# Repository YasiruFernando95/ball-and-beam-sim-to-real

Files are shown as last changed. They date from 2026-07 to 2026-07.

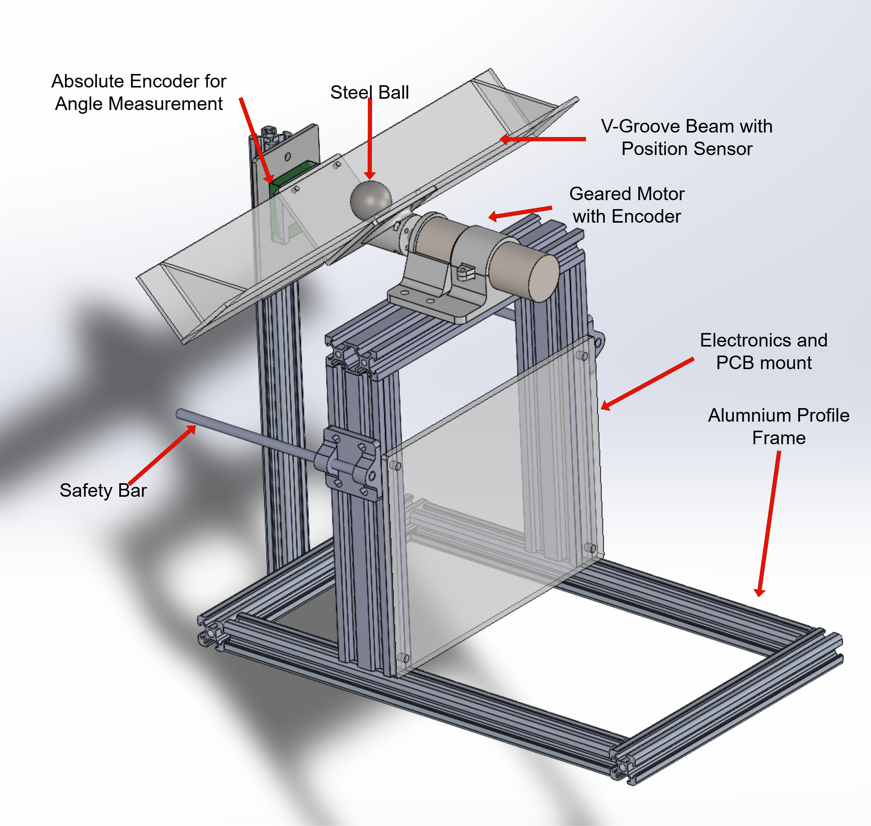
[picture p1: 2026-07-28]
hardware/prototype/diagrams/labelled_diagram.png

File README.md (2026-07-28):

# Ball-and-Beam Control System

A mechatronic ball-and-beam platform developed for classical control, reinforcement-learning control, and simulation-to-real experiments.

The system uses an STM32F401CCU6 microcontroller to regulate the beam angle through a geared DC motor. Ball position, ball velocity, beam angle, beam angular velocity, motor speed, and the commanded beam-angle setpoint are transmitted to a computer through USB CDC for monitoring, training, and evaluation.

Ball-and-beam system

## Project Status

Current status: **Functional experimental platform**

Implemented features:

- [x] Mechanical ball-and-beam platform
- [x] DC motor actuation
- [x] Motor encoder feedback
- [x] MT6816 absolute beam-angle sensing
- [x] Graphite-strip ball-position sensing
- [x] STM32 firmware
- [x] USB CDC telemetry
- [x] Inner PID beam-angle control
- [x] Beam-angle virtual walls and braking
- [x] PC-command timeout protection
- [x] PyBullet/Gymnasium RL simulation environment
- [x] Hardware interface for RL beam-angle commands

## Project Objectives

The project aims to:

- Develop a functional ball-and-beam experimental platform.
- Implement reliable real-time sensing and motor control.
- Train reinforcement-learning agents in a physics-based simulation.
- Transfer trained policies to the physical system.
- Compare classical and reinforcement-learning-based controllers.
- Evaluate tracking accuracy, settling behavior, control effort, robustness, and safety.

## System Overview

The controller changes the angle of a V-groove beam to regulate the position of a steel ball.

| Variable | Description | Unit |
|---|---|---|
| `x` | Ball position measured from the beam center | m |
| `xdot` | Filtered ball velocity | m/s |
| `theta` | Beam angle | degrees |
| `thetadot` | Filtered beam angular velocity | degrees/s |
| `omega` | Filtered geared-motor output speed | degrees/s |
| `theta_sp` | Beam-angle setpoint received from the PC | degrees |
| `u` | Inner PID motor command | normalized `-1` to `+1` |

The firmware executes its main sensing, telemetry, and beam-angle control block every **10 ms**, corresponding to **100 Hz**.

## Hardware

### Main Components

| Component | Model or specification | Purpose |
|---|---|---|
| Microcontroller | STM32F401CCU6 Black Pill | Real-time sensing and control |
| Motor | Cytron IG32E, 430 RPM, 14:1 | Beam actuation |
| Motor driver | Cytron MD10C R3 | Bidirectional motor drive |
| Motor encoder | 98 counts per motor revolution | Motor-speed feedback |
| Beam-angle sensor | MT6816 | Absolute beam-angle measurement |
| Ball-position sensor | Graphite-strip potentiometer | Ball-position measurement |
| Display | 0.96-inch SSD1306 OLED | Local measurements and status |
| Power supply | 12 V, 3 A | System power |
| Ball | 25 mm steel ball | Controlled object |
| Beam | 0.30 m acrylic V-groove | Ball rolling surface |

### Mechanical Specifications

| Parameter | Value |
|---|---:|
| Beam length | 0.30 m |
| Ball diameter | 25 mm |
| Firmware beam-angle limit | -25° to +25° |
| Beam construction | Acrylic V-groove |
| Motor gear ratio | 14:1 |
| Frame material | Aluminium extrusion |

### Firmware Peripheral Assignment

| Function | STM32 peripheral or signal | Purpose |
|---|---|---|
| Motor PWM | TIM3 Channel 1 | Motor command magnitude |
| Motor direction | GPIO PB3 | Motor direction |
| Motor encoder | TIM2 encoder mode | Motor-speed measurement |
| Beam-angle sensor | SPI1 with DMA | MT6816 communication |
| Ball-position sensor | ADC1 Channel 2 with DMA | Position-sensor voltage |
| OLED display | I2C1 with DMA | Local display |
| Control/update timer | TIM10 | Encoder and ADC updates |
| PC communication | USB CDC | Commands and telemetry |

A complete wiring diagram should be placed in:

```text
hardware/schematics/
```

## Firmware Architecture

The firmware uses the following custom modules:

```text
dist_adc
ssd1306
mt6816
encoder_speed
motor_driver
virtual_wall
pid
usb_telemetry
```

The main runtime sequence is:

1. Update the ADC-based ball-position measurement.
2. Read the MT6816 beam angle.
3. Estimate ball and beam velocities using filtered numerical derivatives.
4. Read the latest beam-angle setpoint received through USB CDC.
5. Transmit telemetry to the PC.
6. Apply the ±25° command clamp.
7. Run the inner PID beam-angle controller.
8. Apply the virtual-wall safety function.
9. Drive or brake the motor.

The firmware holds the motor at zero for approximately **5 seconds after startup** before enabling the PID controller.

## Control Architecture

### Inner Beam-Angle Controller

The STM32 runs a PID controller that converts the desired beam angle into a normalized motor command.

```text
Controller: PID
Sample time: 10 ms
Output range: -1.0 to +1.0

Kp = 0.02115
Ki = 0.02104
Kd = 0.0001710
```

The controlled variables are:

```text
Input:     measured beam angle, degrees
Setpoint:  commanded beam angle, degrees
Output:    normalized motor command
```

### Outer Controller

The outer controller runs on the PC and sends a desired beam-angle setpoint to the STM32.

The uploaded firmware supports an RL or other external controller through:

```text
g_thsp_cmd
```

The setpoint is limited to:

```text
-25° <= theta_sp <= +25°
```

The exact incoming USB command syntax is implemented by `USB_Command_Process()` in the USB telemetry module and should be documented after that module is added to the repository.

## Reinforcement-Learning Environment

The project includes a custom Gymnasium-compatible PyBullet environment:

```text
rl/training/ball_beam_env_v2.py
```

The environment class is:

```python
BallBeamCleanEnv
```

It is designed for simulation-to-real training and includes:

- PyBullet rigid-body dynamics
- A 0.30 m beam and 25 mm ball
- Beam end stops
- Measured actuator command delay
- First-order actuator lag
- Beam torque and speed limits
- Setpoint-rate limiting
- End-region recovery behavior
- Centering, smoothness, and safety rewards
- Termination for excessive beam angle
- Truncation for persistent end contact or becoming stuck near an end

The environment follows the Gymnasium interface:

```python
observation, info = env.reset()
observation, reward, terminated, truncated, info = env.step(action)
```

### Simulation Timing

| Parameter | Default |
|---|---:|
| PyBullet physics step | `1/240 s` |
| RL control frequency | `100 Hz` |
| Beam-angle limit | `±25°` |
| Normal initial ball range | `±0.06 m` |
| Initial beam-angle range | `±2°` |

The environment automatically calculates the number of PyBullet physics steps per RL control step.

### Observation Space

By default, the environment returns a six-element observation in raw SI units:

```python
observation = [
    x,
    xdot,
    theta,
    thdot,
    theta_sp_delayed,
    theta_cmd,
]
```

| Observation | Unit | Description |
|---|---|---|
| `x` | m | Ball position along the beam |
| `xdot` | m/s | Ball velocity relative to the rotating beam |
| `theta` | rad | Beam angle |
| `thdot` | rad/s | Beam angular velocity |
| `theta_sp_delayed` | rad | Setpoint after the delay buffer |
| `theta_cmd` | rad | Internal actuator command after lag |

The approximate observation limits are:

| Observation | Range |
|---|---:|
| Ball position | `-x_limit` to `+x_limit` |
| Ball velocity | `-3` to `+3 m/s` |
| Beam angle | `-25°` to `+25°` |
| Beam angular velocity | `-50` to `+50 rad/s` |
| Delayed setpoint | `-25°` to `+25°` |
| Filtered actuator command | `-25°` to `+25°` |

A four-state physical observation can be used by disabling the actuator states:

```python
env.include_actuator_state = False
```

This produces:

```python
[x, xdot, theta, thdot]
```

### Action Space

The RL action is a desired beam-angle setpoint in radians:

```python
action = [theta_setpoint]
```

The action space is:

```python
spaces.Box(
    low=[-theta_limit],
    high=[+theta_limit],
    dtype=np.float32,
)
```

With the default configuration:

```text
theta_setpoint in [-25°, +25°]
```

The policy therefore controls the desired beam angle rather than directly commanding PWM.

### Actuator Model

The simulated actuator uses:

1. A setpoint-rate limit
2. A control-step delay buffer
3. A first-order lag
4. A torque-limited beam-joint controller
5. A simplified torque-speed relationship

Default actuator parameters:

| Parameter | Default |
|---|---:|
| Command delay | 13 control steps |
| Delay at 100 Hz | approximately 0.13 s |
| First-order lag time constant | 0.070 s |
| Normal setpoint-rate limit | 140°/s |
| End-recovery rate limit | 220°/s |
| Approximate stall torque | 0.11 N·m |
| Approximate no-load speed | 45 rad/s |

The delayed setpoint is filtered using:

```python
alpha = ctrl_dt / (servo_tau_s + ctrl_dt)
theta_cmd += alpha * (theta_sp_delayed - theta_cmd)
```

### Reset Distribution

At reset, the environment randomizes the initial beam angle and ball position.

Most episodes begin near the center. By default, approximately 25% of resets may place the ball near one of the ends to train recovery behavior.

The delay buffer and actuator state are initialized to the starting beam angle to reduce unrealistic first-step transients.

### Reward Function

The total reward is formed from:

```python
reward = (
    r_center
    + r_servo
    + r_velocity
    + r_progress
    + r_endzone
    + r_position
    + r_offset
)
```

#### Center Reward

A Gaussian reward encourages the ball to remain close to the beam center:

```python
r_center = exp(-0.5 * (x / sigma) ** 2)
```

Default width:

```text
sigma = 0.020 m
```

#### Position Penalty

A normalized quadratic penalty prevents stable off-center behavior:

```python
r_position = -w_x * (abs(x) / x_limit) ** 2
```

Default:

```text
w_x = 0.35
```

#### Progress Reward

The agent is rewarded for decreasing the absolute ball-position error:

```python
progress = previous_abs_x - current_abs_x
r_progress = w_p * progress / ctrl_dt
```

Default:

```text
w_p = 0.25
```

#### Servo-Movement Penalty

Rapid actuator movement is penalized, particularly near the center:

```python
r_servo = -w_u * center_gate * normalized_command_rate**2
```

Default:

```text
w_u = 0.10
```

#### Near-Center Velocity Penalty

A small ball-velocity penalty encourages true settling rather than repeated center crossings.

Default:

```text
w_v = 0.02
velocity scale = 0.25 m/s
```

#### End-Zone Penalty

A quadratic penalty discourages the agent from remaining near either end.

Default:

```text
w_end = 0.35
end margin = 0.020 m
```

#### Success Bonus

The environment defines successful stabilization as remaining within:

```text
|x| < 0.010 m
```

for:

```text
2.0 s
```

At 100 Hz, this requires approximately 200 consecutive control steps.

The first successful hold receives a bonus of:

```text
10.0
```

### Termination and Truncation

#### Beam-Angle Violation

The episode terminates when:

```text
|theta| > 25°
```

Penalty:

```text
-10
```

Reason:

```text
angle_violation
```

#### Persistent End-Stop Contact

Each end-stop contact receives a penalty of `-5`.

The episode is truncated after:

```text
200 consecutive contact steps
```

At 100 Hz, this is approximately 2 seconds.

Reason:

```text
end_contact
```

#### Ball Stuck Near an End

A stuck counter increases when the ball is in the end zone and:

```text
|xdot| < 0.012 m/s
```

The episode is truncated after:

```text
300 consecutive stuck steps
```

At 100 Hz, this is approximately 3 seconds.

Reason:

```text
end_stuck
```

#### Episode Time Limit

The environment does not currently implement a fixed maximum duration internally. Apply Gymnasium's `TimeLimit` wrapper:

```python
env = gym.wrappers.TimeLimit(
    BallBeamCleanEnv(),
    max_episode_steps=2000,
)
```

At 100 Hz, 2000 steps correspond to approximately 20 seconds.

### Episode Metrics

The `info` dictionary includes:

```text
x
xdot
theta
thdot
theta_sp
theta_sp_delayed
theta_cmd
hit_endstop
angle_violation
done_reason
```

At the end of an episode, it also includes:

```text
metrics/success
metrics/settling_time_s
metrics/max_overshoot_m
metrics/band_m
metrics/hold_s
```

`metrics/max_overshoot_m` currently represents the maximum absolute ball-position excursion during the episode.

### Example Environment Usage

```python
import gymnasium as gym
from ball_beam_pybullet_env import BallBeamCleanEnv

env = BallBeamCleanEnv(
    render_mode="human",
    ctrl_hz=100.0,
    theta_limit_deg=25.0,
)

env = gym.wrappers.TimeLimit(
    env,
    max_episode_steps=2000,
)

observation, info = env.reset(seed=42)
terminated = False
truncated = False

while not terminated and not truncated:
    action = env.action_space.sample()
    observation, reward, terminated, truncated, info = env.step(action)

print(info)
env.close()
```

## Repository Structure

```text
ball-and-beam/
├── README.md
├── LICENSE
├── .gitignore
├── firmware/
│   ├── mcu/
│	│	├── cascaded pid/
│	│	└── rl pid hybrid/
│   ├── python/
│	│	├── cascaded pid data logger/
│	│	├── pybullet simulation data logger/
│	│	└── rl pid hybrid data logger/
│	└── README.md
├── hardware/
│   ├── prototype/
│	│	├── cad/
│	│	├── diagrams/
│   └── schematics/
├── rl/
│   ├── training/
│   ├── system id/
│   ├── models/
│   ├── logs/
│   └── README.md
└── experiments/
	├── experiment_a/
	├── experiment_b/
	├── experiment_c/
	├── results_experiment_a/
	├── results_experiment_b/
	├── results_experiment_c/
	├── plot_results.py
    └── README.md

```

## Installation

### Firmware Requirements

- STM32CubeIDE: `[1.18.1]`
- STM32F4 HAL drivers
- USB Device middleware
- SSD1306 display library
- Project-specific sensor, motor, PID, and telemetry modules

Read the README.md file in the firmware folder before continuing

Build and flash the relelvant firmware to the STM32F401CCU6.

### Python Requirements

Recommended Python version:

```text
Python 3.10 or 3.11
```

Create and activate a virtual environment:

```bash
python -m venv .venv
```

Windows:

```bash
.venv\Scripts\activate
```

Linux or macOS:

```bash
source .venv/bin/activate
```

Install the required packages:

```text
numpy
pandas
matplotlib
pyserial
gymnasium
pybullet
stable-baselines3
torch
```

Remove packages that are not used by the final repository.

## Running the Hardware

1. Inspect the beam, ball, sensor strip, and motor mechanism.
2. Place the beam near its neutral position.
3. Connect the STM32 through USB.
4. Connect the 12 V motor supply.
5. Confirm that the MT6816 angle is reasonable.
6. Confirm that the virtual-wall limits are ±25°.
7. Start the PC controller and begin sending beam-angle commands.
8. Stop operation immediately if the measured angle or motor direction is incorrect.

The firmware waits approximately 5 seconds before enabling motor control.

## Communication Protocol

### STM32-to-PC Telemetry

The STM32 sends one newline-terminated ASCII telemetry record every 10 ms:

```text
X:<x_m>,XD:<xdot_m_s>,TH:<theta_deg>,THD:<thetadot_deg_s>,W:<motor_speed_deg_s>,ANG:<setpoint_deg>
```

Example:

```text
X:-0.0342,XD:0.1285,TH:3.417,THD:-5.231,W:42.580,ANG:4.000
```

| Field | Unit | Description |
|---|---|---|
| `X` | m | Ball position relative to the center |
| `XD` | m/s | Filtered ball velocity |
| `TH` | degrees | Measured beam angle |
| `THD` | degrees/s | Filtered beam angular velocity |
| `W` | degrees/s | Filtered geared-motor output speed |
| `ANG` | degrees | Latest beam-angle setpoint received from the PC |

The transmitted values are generated from the current firmware state. `ANG` reports the latest received command variable; the motor-side setpoint is subsequently forced to zero if the command timeout expires.

### PC-to-STM32 Commands

Incoming USB CDC data are passed to:

```c
USB_Command_Process(buf, len);
```

The command updates the global beam-angle setpoint used by the hardware controller.

The exact command-string syntax is defined in the `usb_telemetry` source files and should be documented here after those files are added.

### Command Timeout

If no valid command update is received for more than:

```text
100 ms
```

the firmware changes the active beam-angle setpoint to:

```text
0°
```

## Calibration and Firmware Constants

### MT6816 Beam-Angle Zero

Current zero count:

```text
8344
```

The raw 14-bit encoder value is wrapped around zero and converted using:

```text
360 / 16384 degrees per count
```

This value is hardware-specific.

### Ball-Position Sensor

Current ADC configuration:

```text
Reference voltage:       3.3 V
Resolution:              12 bit
Low calibration voltage: 0.64 V
Mid calibration voltage: 1.84 V
High calibration voltage:2.97 V
Inversion:               disabled
Gamma:                   1.0
Filter alpha:            0.1
DMA buffer length:       64 samples
```

The normalized distance is converted to a centered coordinate using:

```c
x_norm = 2 * distance - 1;
x_m = -0.1375 * x_norm;
```

The resulting nominal position range is approximately:

```text
-0.1375 m to +0.1375 m
```

The sign convention is defined by the negative scale factor.

Repeated use of the graphite and copper strips will degrade the position sensor. Therefore, it is advisable to recalibrate the position sensor after significant usage. In case of unusual readings, it is recommended to replace the graphite and copper strips.

### Velocity Estimation

Ball and beam velocities use a numerical derivative followed by a first-order low-pass update:

```c
filtered += DERIV_ALPHA * (raw_derivative - filtered);
```

Current values:

```text
DT = 0.01 s
DERIV_ALPHA = 0.25
```

### Motor Encoder

```text
Counts per motor revolution: 98
Gear ratio:                  14:1
Output-speed LPF cutoff:     2 Hz
```

### Beam-Angle PID

```text
Kp = 0.02115
Ki = 0.02104
Kd = 0.0001710
Sample time = 10 ms
Output limits = -1 to +1
```

## Safety Features

The uploaded firmware includes:

- Beam-angle command clamping to ±25°
- Virtual-wall protection based on measured beam angle
- PID integrator reset when the virtual wall blocks motion
- Speed-proportional braking near a blocked limit
- Motor command saturation
- A 100 ms PC-command timeout
- A 5-second startup motor-disable period
- Zero motor output while the inner controller is disabled

The virtual-wall braking command is based on:

```c
brake = -0.2 * motor_speed_rad_s;
```

and is limited to:

```text
-1.0 to +1.0
```

Do not operate the system until the beam-angle sign, motor direction, encoder zero, and virtual-wall response have been checked.

In addition, phyical side bars have been installed on the setup to prevent the beam from continuous rotation. Continuous rotation may tangle the absolute encoder cable and damage electrical connections

## Known Limitations

- The graphite-strip ball-position sensor may introduce noise and nonlinearities.
- Ball and beam velocities are estimated using filtered numerical derivatives.
- The actuator model is a simplified delay, lag, and torque-speed approximation.
- Friction, ball mass, delay, and sensor noise are not yet randomized.
- The environment uses optional end-recovery delay relief that reduces strict actuator realism.
- The RL target is fixed at the beam center.
- The environment does not implement its own maximum episode duration.
- The firmware telemetry does not include the inner PID output.

## Planned Improvements

- Improve position sensing mechanism to a robust solution less susceptible to wear, degradation and long term drift.
- Investigate hardware aware fine tuning
- Compare multiple RL algorithms on the same platform.
- Apply full RL-based control by allowing policy to output direct motor commands
- Add configurable target trajectories.

## Citation

```bibtex
@misc{fernando_ball_beam_2026,
  author    = {Yasiru Suharshana Fernando},
  title     = {Ball-and-Beam Control System},
  year      = {2026},
  publisher = {GitHub},
  url       = {[repository URL]}
}
```

## License

This project is licensed under the **[choose a license]**.

See the `LICENSE` file for details.

## Authors

**Yasiru Suharshana Fernando**

PhD Candidate in Mechatronics and Machine Intelligence
Faculty of Advanced Science and Technology  
Asian Institute of Technology  

- Email: `[st125391@ait.asia, yasiruf@yahoo.co.uk]`
- ORCID: `[https://orcid.org/0009-0000-1786-4137]`
- Website: `[https://yasirufernando.com/]`
- LinkedIn: `[https://www.linkedin.com/in/yasirufernando/]`

**Narong Aphiratsakun**

Dean of the Faculty of Engineering, Science and Technology 
Assumption University, Bangkok

- Email: `[narongphr@au.edu]`
- ORCID: `[https://orcid.org/0009-0009-0956-7656]`

**Xavier Jonathon Blake**

PhD Candidate in Mechatronics and Machine Intelligence
Faculty of Advanced Science and Technology  
Asian Institute of Technology  

- Email: `[xavierjblake@gmail.com]`
- ORCID: `[https://orcid.org/0009-0008-8639-558X]`

## Acknowledgements

The authors would like to express their sincere gratitude to Assumption University of Thailand and the Asian Institute of Technology for their support and institutional assistance throughout this research.

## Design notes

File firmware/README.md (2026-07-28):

# Firmware and PC Software

This folder contains two matched MCU–Python software pairs. Use files from the same pair together, because the communication format and controller responsibilities are different.

## Folder Structure

```text
firmware/
├── mcu/
│   ├── cascaded pid/
│   └── rl pid hybrid/
└── python/
    ├── cascaded pid data logger/
	├── pybullet simulation data logger/
    └── rl pid hybrid data logger/
```

## Baseline Cascaded PID

Use the following pair:

```text
mcu/cascaded pid/
python/cascaded pid data logger/
```

In this configuration, the STM32 runs both control loops:

* Outer ball-position PID
* Inner beam-angle PID

The Python software is mainly used for:

* Sending reference positions
* Monitoring telemetry
* Recording experimental data
* Plotting system responses

Use this pair for conventional PID testing and as the baseline for comparison with reinforcement learning.

## RL–PID Hybrid

Use the following pair:

```text
mcu/rl pid hybrid/
python/rl pid hybrid data logger/
```

In this configuration:

* The Python RL policy acts as the outer controller.
* The RL policy generates a desired beam-angle setpoint.
* The STM32 runs the inner beam-angle PID controller.
* The STM32 applies motor control, command limits, virtual-wall protection, and communication-timeout safety.

Use this pair for trained-policy evaluation and simulation-to-real experiments.

## PyBullet Simulation

To generate simulation data, use the following folder.

```text
python/rl pid hybrid data logger/
```

## Important

Do not mix the MCU firmware from one configuration with the Python software from the other configuration. Their command and telemetry handling may not be compatible.

Before running either configuration:

1. Flash the matching STM32 project.
2. Run the corresponding Python program.
3. Check the configured serial port.
4. Confirm the beam-angle zero and motor direction.
5. Verify that the beam-angle safety limits are active.

Refer to the README inside each subfolder for configuration-specific instructions.

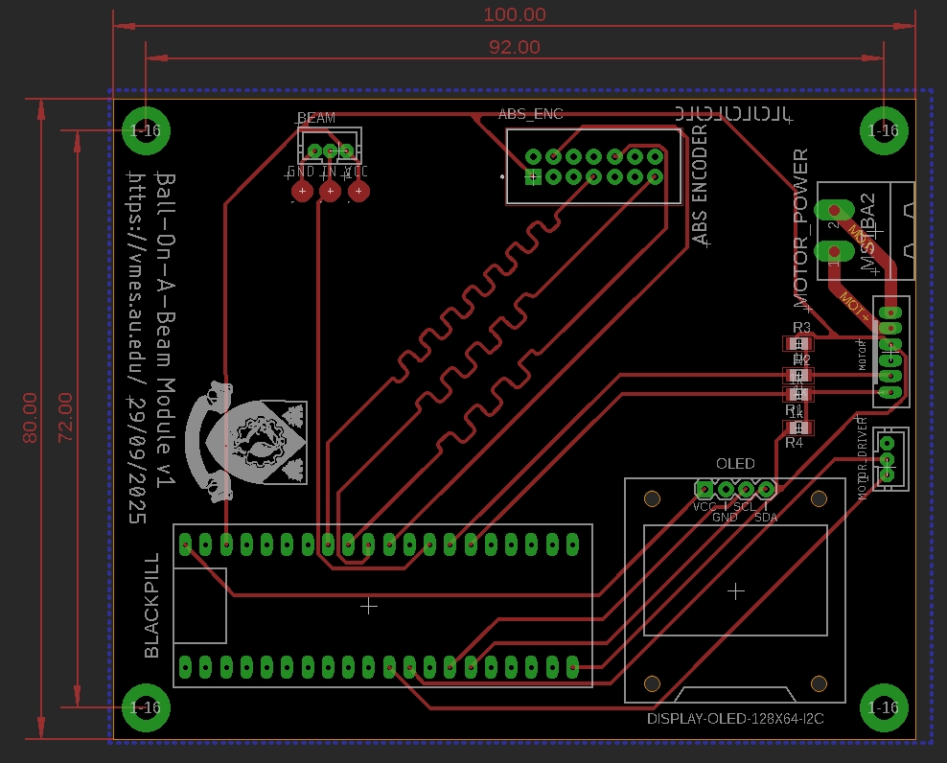
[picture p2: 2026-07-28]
hardware/schematics/pcb.jpg

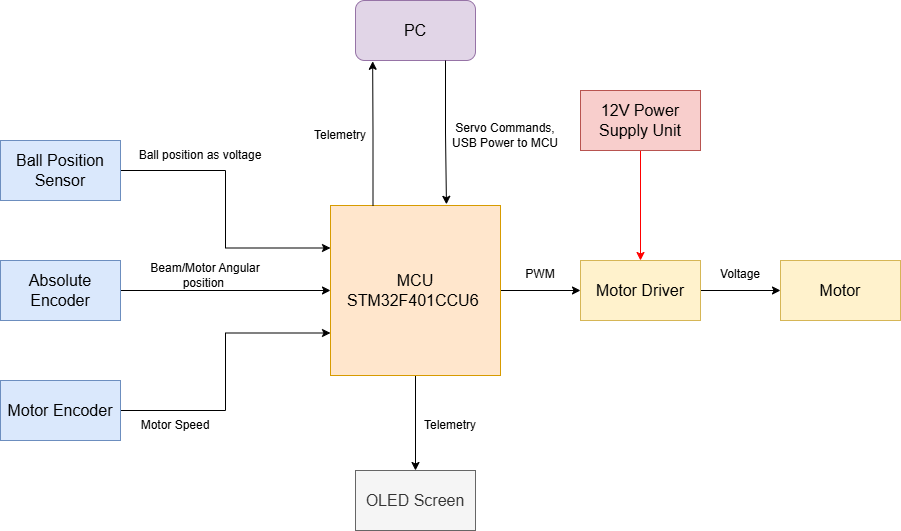
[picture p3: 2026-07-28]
hardware/schematics/electrical_system.png

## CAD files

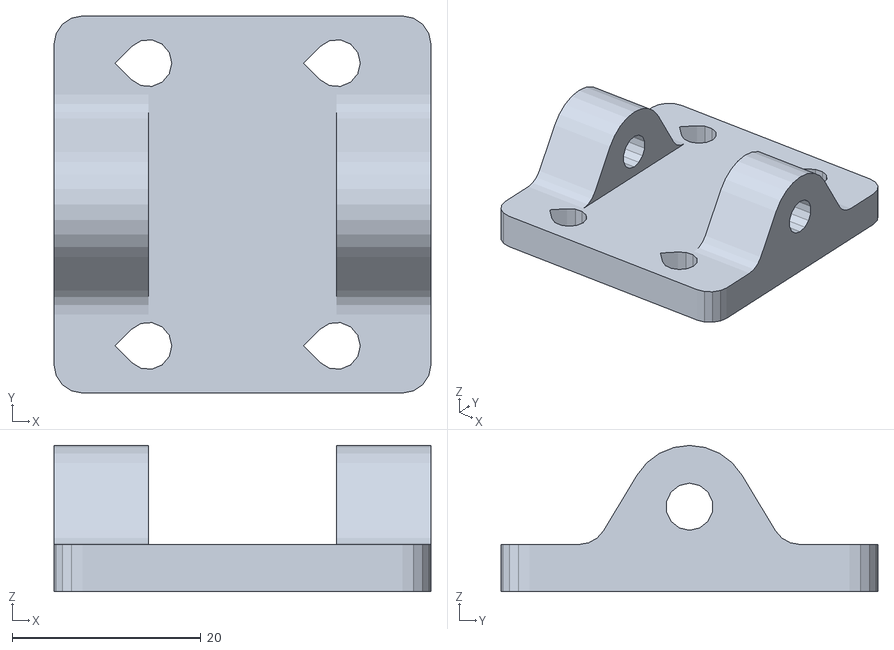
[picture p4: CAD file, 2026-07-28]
hardware/prototype/cad/stl/stopper_holder_v2.STL
40.0 x 40.0 x 15.5

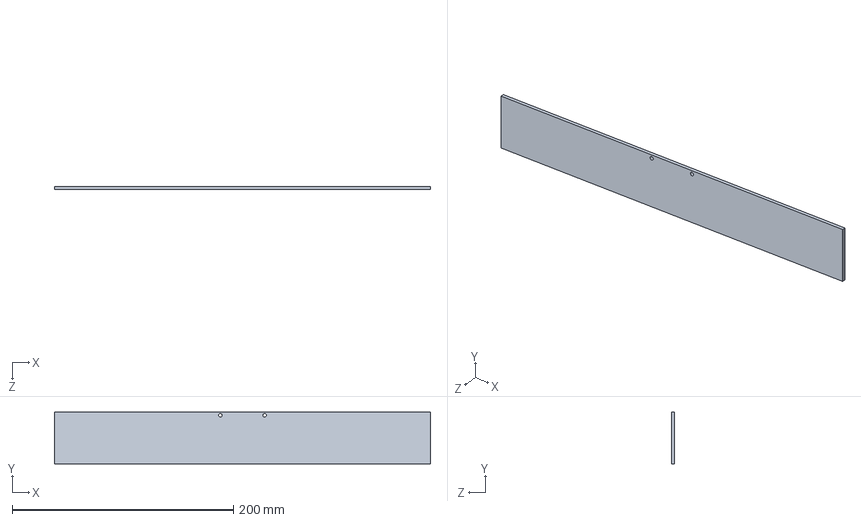
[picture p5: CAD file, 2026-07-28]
hardware/prototype/cad/acrylic_2.SLDPRT
340.0 x 47.0 x 3.00 mm

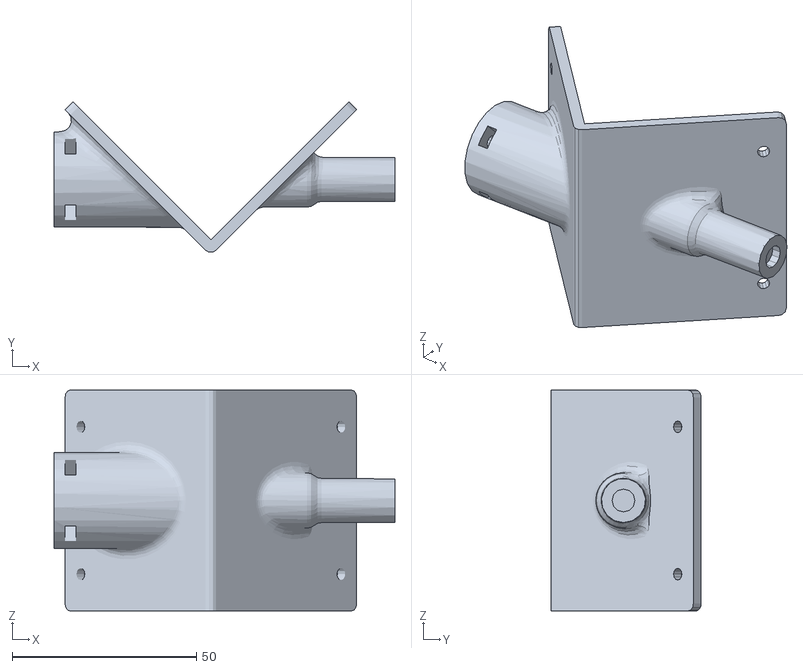
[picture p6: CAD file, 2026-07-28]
hardware/prototype/cad/stl/motor_interface_v3.STL
92.6 x 40.8 x 60.0

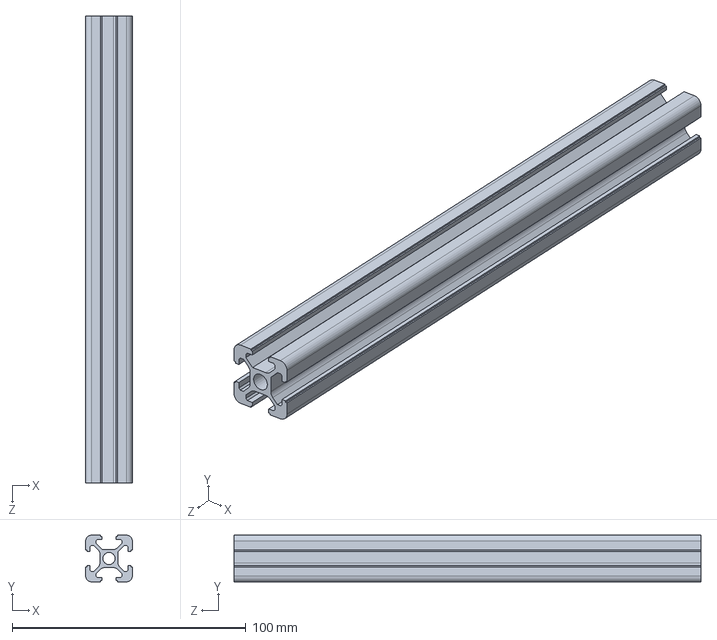
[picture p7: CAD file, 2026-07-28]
hardware/prototype/cad/Aluminum profile 20x20 160mm.SLDPRT
20.0 x 20.0 x 200.0 mm

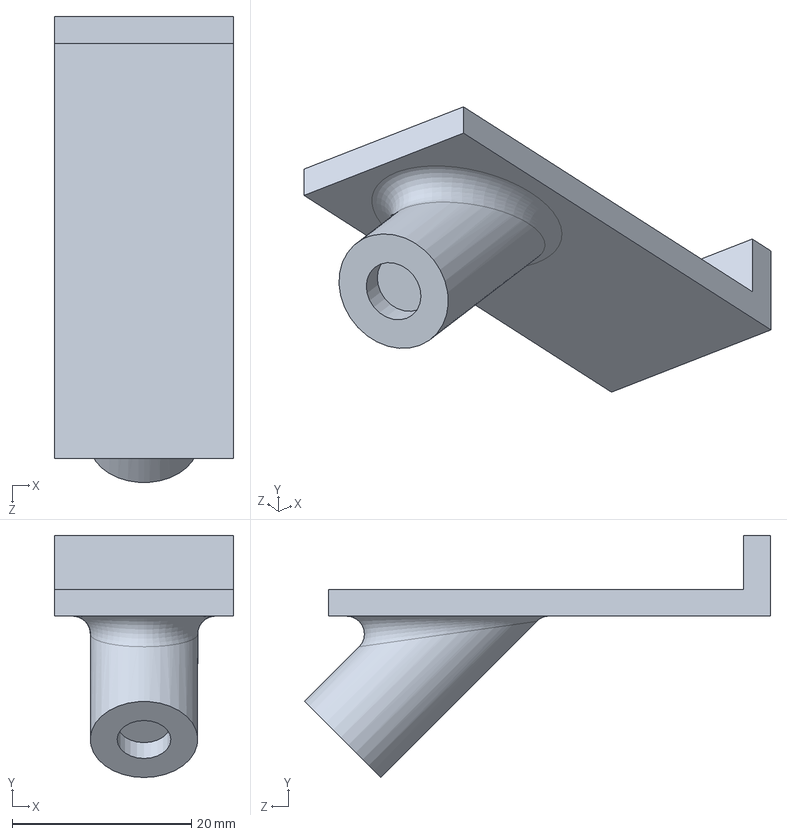
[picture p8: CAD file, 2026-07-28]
hardware/prototype/cad/magnet_mount.SLDPRT
20.0 x 27.0 x 52.0 mm

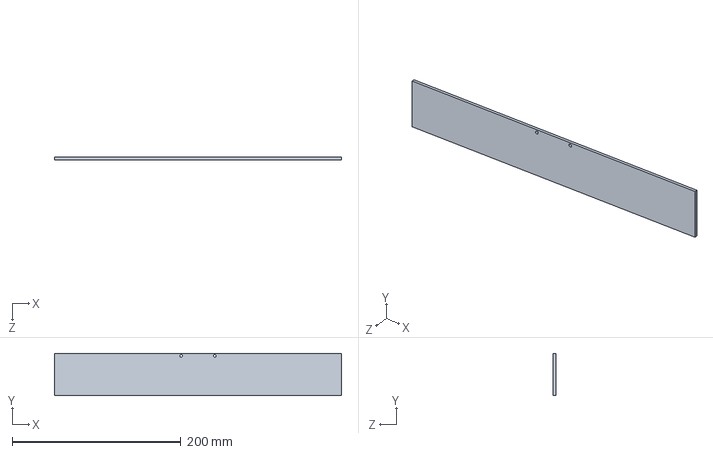
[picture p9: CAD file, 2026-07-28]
hardware/prototype/cad/acrylic_1.SLDPRT
340.0 x 50.0 x 3.00 mm

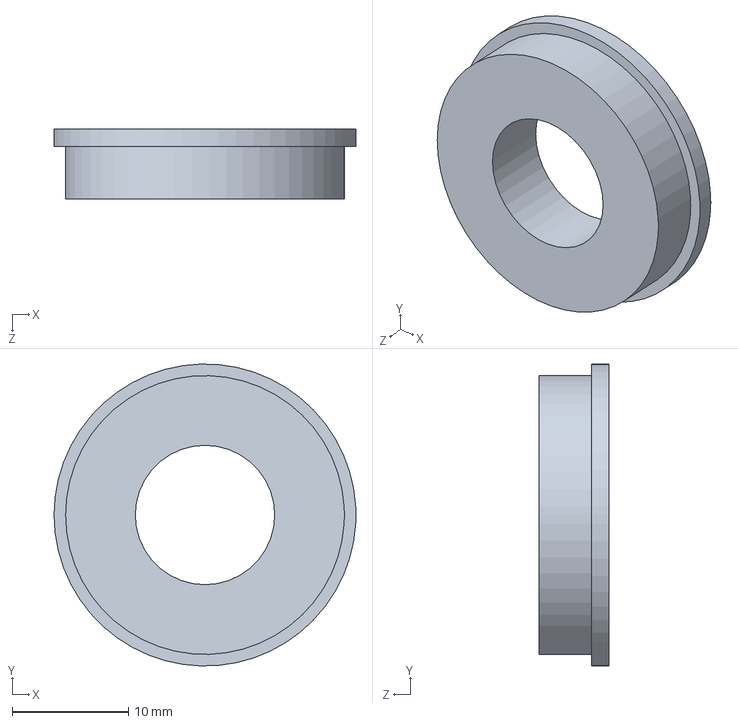
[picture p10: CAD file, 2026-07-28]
hardware/prototype/cad/bearing.SLDPRT
26.0 x 26.0 x 6.00 mm

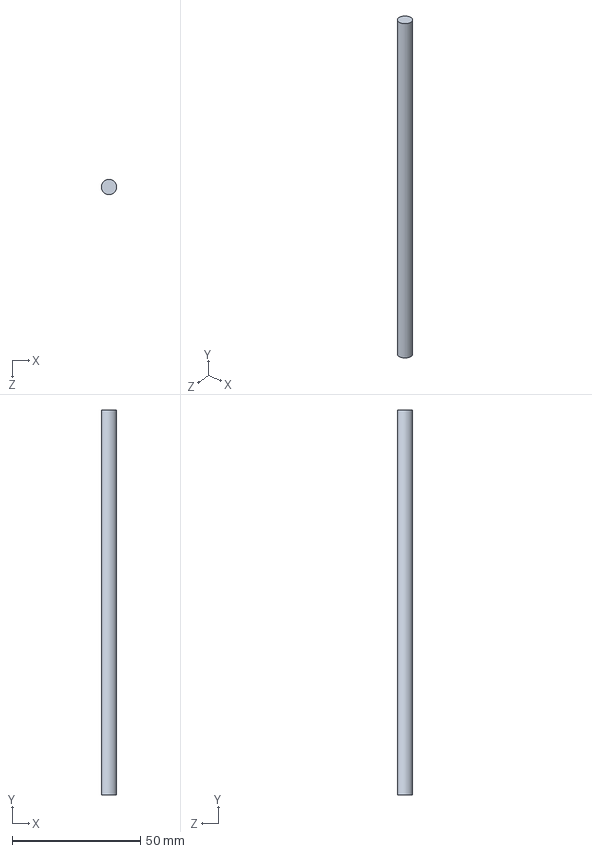
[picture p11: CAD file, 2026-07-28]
hardware/prototype/cad/stopper_bar.SLDPRT
6.00 x 150.0 x 6.00 mm

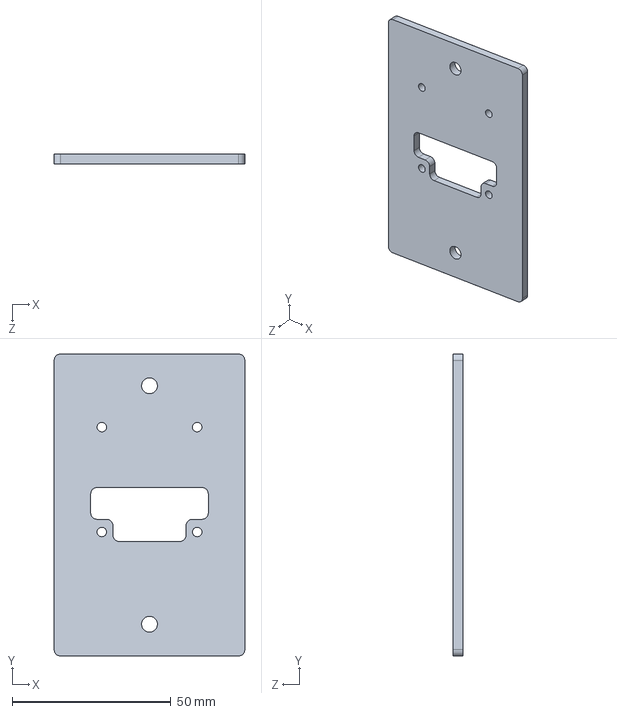
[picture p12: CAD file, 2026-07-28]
hardware/prototype/cad/encoder_mount.SLDPRT
60.0 x 95.0 x 3.00 mm

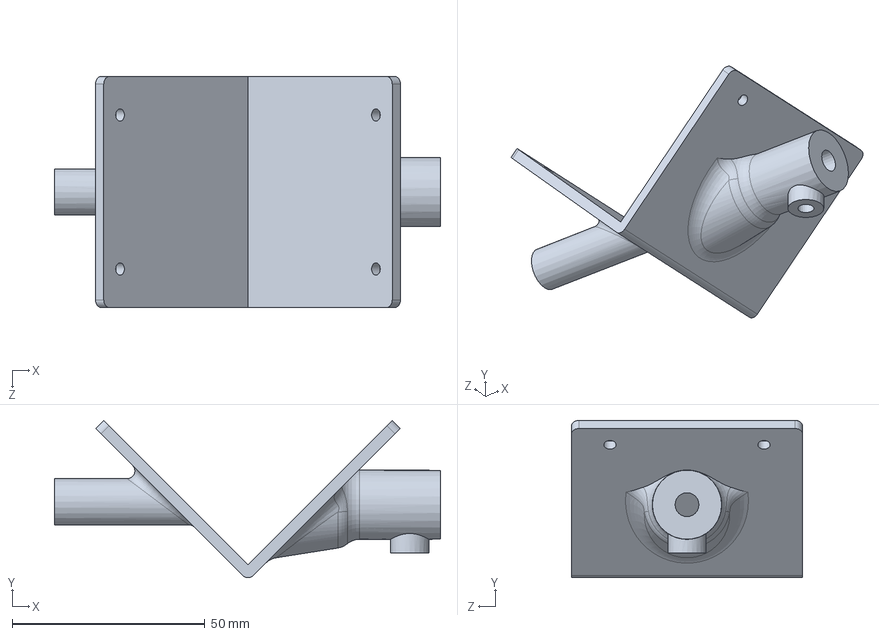
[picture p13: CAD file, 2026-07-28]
hardware/prototype/cad/motor_interface.SLDPRT
100.3 x 40.9 x 60.0 mm

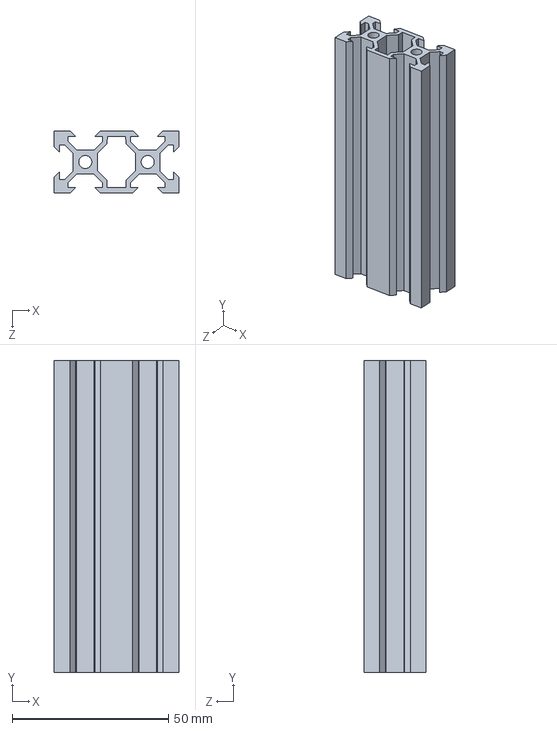
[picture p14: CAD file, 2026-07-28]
hardware/prototype/cad/profile 2040.SLDPRT
40.0 x 100.0 x 20.0 mm

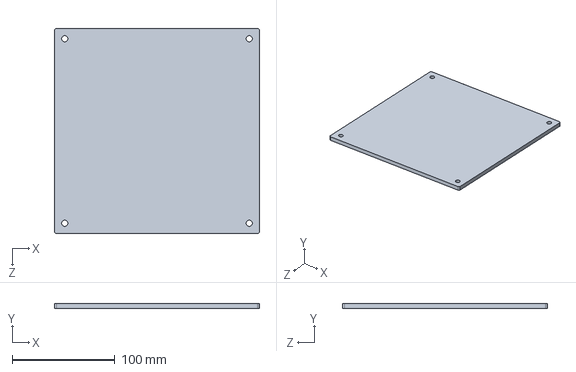
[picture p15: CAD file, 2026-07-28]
hardware/prototype/cad/acrylic_plate.SLDPRT
200.0 x 5.00 x 200.0 mm

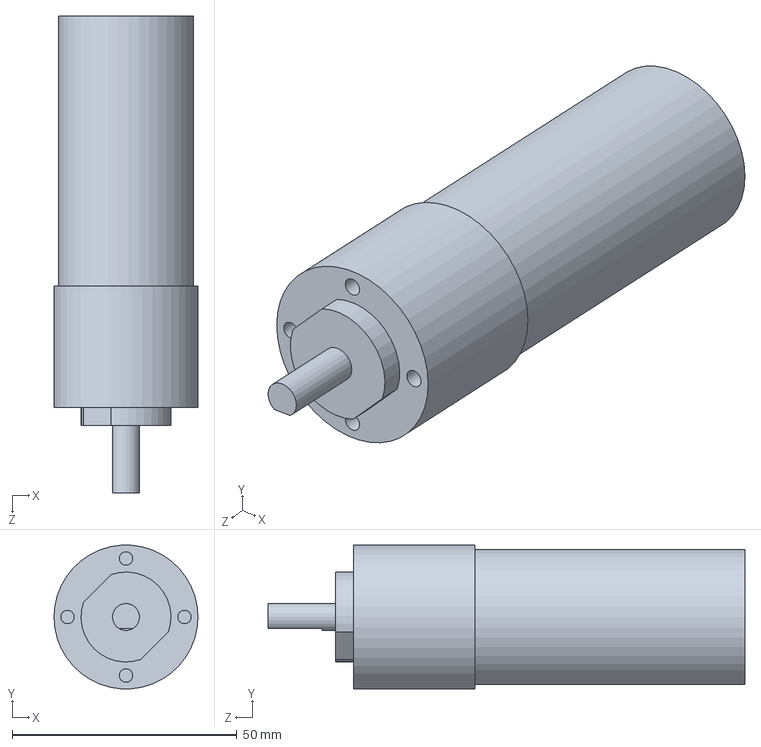
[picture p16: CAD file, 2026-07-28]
hardware/prototype/cad/motor.SLDPRT
32.0 x 31.9 x 106.0 mm

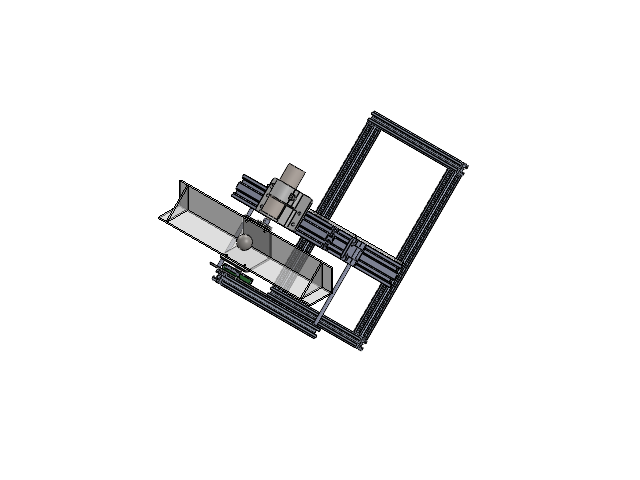
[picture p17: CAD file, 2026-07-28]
hardware/prototype/cad/body_assembly.SLDASM
acrylic_1
acrylic_2
steel_ball
acrylic_3 x 2
motor
motor_mount_base
motor_mount_top
profile 2040 x 3
Aluminum profile 20x20 400mm x 3
acrylic_plate
Aluminum profile 20x20 160mm x 2
encoder_mount
encoder_mockup
bearing
bearing_mount
stopper_holder x 2
stopper_bar x 2
motor_mount_flange
motor_interface_v2

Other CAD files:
hardware/prototype/cad/stopper_holder.SLDPRT
hardware/prototype/cad/bearing_mount.SLDPRT
hardware/prototype/cad/motor_mount_base.SLDPRT
hardware/prototype/cad/motor_mount_top.SLDPRT
hardware/prototype/cad/Aluminum profile 20x20 400mm.SLDPRT
hardware/prototype/cad/acrylic_3.SLDPRT
hardware/prototype/cad/encoder_mockup.SLDPRT
hardware/prototype/cad/motor_interface_v2.SLDPRT
hardware/prototype/cad/motor_mount_flange.SLDPRT
hardware/prototype/cad/steel_ball.SLDPRT
hardware/prototype/cad/stl/bearing_mount.STL
hardware/prototype/cad/stl/encoder_mount.STL
hardware/prototype/cad/stl/magnet_mount.3mf
hardware/prototype/cad/stl/motor_mount_base.STL
hardware/prototype/cad/stl/motor_mount_top.STL

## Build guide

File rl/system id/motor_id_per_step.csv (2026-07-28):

dataset | phase | u_cmd | w0 | wss | K_degps_per_u | tau_s | n
NO_LOAD | STEP_NEG_0.100 | -0.1 | -6.814 | 0.0 | -68.14 | 0.36651527206096707 | 402
NO_LOAD | STEP_NEG_0.150 | -0.15 | -3.726 | 0.0 | -24.84 | 0.40727162136071887 | 402
NO_LOAD | STEP_NEG_0.200 | -0.2 | -3.082 | 0.0 | -15.409999999999998 | 0.22548401883517388 | 400
NO_LOAD | STEP_POS_0.100 | 0.1 | 1.406 | 0.0 | -14.059999999999999 | 0.4523773910396083 | 400
NO_LOAD | STEP_POS_0.150 | 0.15 | 1.007 | 0.0 | -6.713333333333333 | 1.8578195959961736 | 402
NO_LOAD | STEP_POS_0.200 | 0.2 | 1.199 | 0.0 | -5.995 | 0.43046210052033307 | 402
BEAM_LOAD | STEP_NEG_0.100 | -0.1 | -3.548 | 0.0 | -35.48 | 0.9549296900753638 | 401
BEAM_LOAD | STEP_NEG_0.150 | -0.15 | -4.716 | 0.0 | -31.44 | 0.3141118920586969 | 401
BEAM_LOAD | STEP_NEG_0.200 | -0.2 | -5.175 | 0.0 | -25.874999999999996 | 0.3518954249707075 | 401
BEAM_LOAD | STEP_POS_0.100 | 0.1 | 3.162 | 0.0 | -31.619999999999997 | 0.45819154068648366 | 400
BEAM_LOAD | STEP_POS_0.150 | 0.15 | 7.671 | 0.0 | -51.14 | 0.3660232310175849 | 402
BEAM_LOAD | STEP_POS_0.200 | 0.2 | 4.0215 | 0.0 | -20.107499999999998 | 0.4450891639586092 | 401

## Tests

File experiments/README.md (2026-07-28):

# Experiment Descriptions

This folder contains the datasets and results for three experiments used to compare the cascaded PID hardware controller, the Hybrid RL–PID hardware controller, and the reinforcement-learning simulation.

For all experiments, the target ball position is the center of the beam.

```text
Reference position: 0 m
Deadband: ±0.010 m
Trial duration: approximately 30 s
```

The deadband allows the controller to balance the ball within ±10 mm of the center rather than at one exact point. 

## Experiment A — Ball Starts at the Center

The ball is initially placed near the center of the beam before the controller is enabled.

The purpose of this experiment is to evaluate steady balancing performance when the system begins close to equilibrium. It is used to observe position stability, small oscillations, drift, beam-angle activity, controller jitter, and the control effort required to maintain balance.

Data are collected for approximately 30 seconds after enabling the controller. The experiment is repeated 10 times for each control method, and the results are averaged to evaluate consistency. 

## Experiment B — Ball Starts Away from the Center

The ball is initially placed approximately 0.10 m from the center of the beam on either the positive or negative side.

Before the outer controller is enabled, the beam is held approximately horizontal using the inner beam-angle PID loop. The PID or Hybrid RL outer controller is then activated and attempts to move the ball toward the center.

The purpose of this experiment is to evaluate recovery from a large initial position error, transient response, settling time, maximum position error, and control effort during recovery.

Each trial runs for up to approximately 30 seconds. The experiment is repeated 10 times for each controller. The simulation is configured to reproduce a similar initial offset condition. 

## Experiment C — Ball Starts at the Center with Disturbances

The ball initially starts near the center of the beam, as in Experiment A.

During the approximately 30-second trial, external positional disturbances are manually applied to the ball.

```text
First disturbance: approximately 5–10 s
Second disturbance: approximately 15–20 s
```

The second disturbance is applied in the opposite direction from the first.

The purpose of this experiment is to evaluate disturbance rejection, recovery behavior, robustness, settling after external disturbances, and changes in controller effort during recovery.

The experiment is repeated 5 times for each controller, and the results are averaged. Because the disturbances are applied manually, their exact magnitude and timing cannot be reproduced identically between trials. The results should therefore be interpreted statistically rather than as perfectly matched individual tests. 

## Evaluation Metrics

The following metrics are calculated for each experiment:

| Metric | Description |
| --- | --- |
| RMSE | Root mean square ball-position error |
| MAE | Mean absolute ball-position error |
| Maximum error  | Largest absolute deviation from the center |
| Settling time  | Time required to enter and remain within the ±10 mm deadband |
| Control effort | Accumulated magnitude or variation of the beam-angle command |

Results are reported using the mean and standard deviation across repeated trials.

```text
mean ± standard deviation
```

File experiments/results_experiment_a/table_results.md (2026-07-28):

# Performance Comparison Results

| Metric | RL | PID | Improvement | p-value |
|---|----|----|---|---|
| RMSE (mm) | 9.92 ± 2.96 | 7.25 ± 4.43 | -36.7% | 0.2634 |
| MAE (mm) | 7.23 ± 1.79 | 6.81 ± 4.31 | -6.1% | 0.8250 |
| Max Error (mm) | 34.60 ± 12.18 | 15.17 ± 13.03 | -128.2% | 0.0235 |
| Settling Time (s) | 3.09 ± 1.79 | 3.86 ± 5.58 | +19.8% | 0.7024 |
| Control Effort (deg) | 138.96 ± 67.73 | 15.60 ± 26.64 | -790.9% | 0.0018 |

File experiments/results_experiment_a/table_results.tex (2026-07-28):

\begin{table}[h]
\centering
\caption{Performance Comparison (mean $\pm$ std)}
\label{tab:performance}
\begin{tabular}{lccc}
\hline
Metric & RL & PID & Improvement \\
\hline
RMSE (mm) & $9.92 \pm 2.96$ & $7.25 \pm 4.43$ & $-36.7\%$ \\
MAE (mm) & $7.23 \pm 1.79$ & $6.81 \pm 4.31$ & $-6.1\%$ \\
Max Error (mm) & $34.60 \pm 12.18$ & $15.17 \pm 13.03$ & $-128.2\%^{*}$ \\
Settling Time (s) & $3.09 \pm 1.79$ & $3.86 \pm 5.58$ & $+19.8\%$ \\
Control Effort (deg) & $138.96 \pm 67.73$ & $15.60 \pm 26.64$ & $-790.9\%^{**}$ \\
\hline
\multicolumn{4}{l}{\footnotesize $^{*}p<0.05$, $^{**}p<0.01$, $^{***}p<0.001$} \\
\end{tabular}
\end{table}

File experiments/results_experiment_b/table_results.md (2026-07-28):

# Performance Comparison Results

| Metric | RL | PID | Improvement | p-value |
|---|----|----|---|---|
| RMSE (mm) | 36.49 ± 12.34 | 21.15 ± 1.68 | -72.6% | 0.0045 |
| MAE (mm) | 22.17 ± 10.35 | 13.36 ± 3.52 | -65.9% | 0.0585 |
| Max Error (mm) | 128.79 ± 9.81 | 109.66 ± 18.54 | -17.4% | 0.0260 |
| Settling Time (s) | 11.22 ± 5.51 | 7.73 ± 2.49 | -45.0% | 0.1175 |
| Control Effort (deg) | 221.32 ± 67.13 | 131.52 ± 41.74 | -68.3% | 0.0027 |

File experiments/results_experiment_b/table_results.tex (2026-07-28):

\begin{table}[h]
\centering
\caption{Performance Comparison (mean $\pm$ std)}
\label{tab:performance}
\begin{tabular}{lccc}
\hline
Metric & RL & PID & Improvement \\
\hline
RMSE (mm) & $36.49 \pm 12.34$ & $21.15 \pm 1.68$ & $-72.6\%^{**}$ \\
MAE (mm) & $22.17 \pm 10.35$ & $13.36 \pm 3.52$ & $-65.9\%$ \\
Max Error (mm) & $128.79 \pm 9.81$ & $109.66 \pm 18.54$ & $-17.4\%^{*}$ \\
Settling Time (s) & $11.22 \pm 5.51$ & $7.73 \pm 2.49$ & $-45.0\%$ \\
Control Effort (deg) & $221.32 \pm 67.13$ & $131.52 \pm 41.74$ & $-68.3\%^{**}$ \\
\hline
\multicolumn{4}{l}{\footnotesize $^{*}p<0.05$, $^{**}p<0.01$, $^{***}p<0.001$} \\
\end{tabular}
\end{table}

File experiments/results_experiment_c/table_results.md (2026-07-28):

# Performance Comparison Results

| Metric | RL | PID | Improvement | p-value |
|---|----|----|---|---|
| RMSE (mm) | 37.51 ± 11.04 | 23.76 ± 5.17 | -57.9% | 0.1039 |
| MAE (mm) | 25.93 ± 8.30 | 13.73 ± 2.02 | -88.9% | 0.0551 |
| Max Error (mm) | 110.22 ± 25.12 | 121.08 ± 23.35 | +9.0% | 0.5714 |
| Settling Time (s) | 6.53 ± 9.69 | 9.96 ± 4.67 | +34.4% | 0.6168 |
| Control Effort (deg) | 239.09 ± 35.77 | 221.32 ± 41.09 | -8.0% | 0.6441 |

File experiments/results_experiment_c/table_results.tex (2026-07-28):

\begin{table}[h]
\centering
\caption{Performance Comparison (mean $\pm$ std)}
\label{tab:performance}
\begin{tabular}{lccc}
\hline
Metric & RL & PID & Improvement \\
\hline
RMSE (mm) & $37.51 \pm 11.04$ & $23.76 \pm 5.17$ & $-57.9\%$ \\
MAE (mm) & $25.93 \pm 8.30$ & $13.73 \pm 2.02$ & $-88.9\%$ \\
Max Error (mm) & $110.22 \pm 25.12$ & $121.08 \pm 23.35$ & $+9.0\%$ \\
Settling Time (s) & $6.53 \pm 9.69$ & $9.96 \pm 4.67$ & $+34.4\%$ \\
Control Effort (deg) & $239.09 \pm 35.77$ & $221.32 \pm 41.09$ & $-8.0\%$ \\
\hline
\multicolumn{4}{l}{\footnotesize $^{*}p<0.05$, $^{**}p<0.01$, $^{***}p<0.001$} \\
\end{tabular}
\end{table}

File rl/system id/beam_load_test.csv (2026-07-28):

t_s | test_name | test_run_id | test_active | phase_label | u_target | u_sent | x | xdot | th_deg | thdot_deg_s | w_deg_s | raw
0.006546 | BEAM_LOAD | 1 | 0 | STOPPED | 0.000000 | 0.000000 | -0.127800 | -0.001200 | 0.396000 | 0.000000 | 0.000000 | X:-0.1278,XD:-0.0012,TH:0.396,THD:0.000,W:0.000,U:0.000
0.016310 | BEAM_LOAD | 1 | 0 | STOPPED | 0.000000 | 0.000000 | -0.127800 | -0.001200 | 0.396000 | 0.000000 | 0.000000 | X:-0.1278,XD:-0.0012,TH:0.396,THD:0.000,W:0.000,U:0.000
0.026355 | BEAM_LOAD | 1 | 0 | STOPPED | 0.000000 | 0.000000 | -0.127800 | -0.001200 | 0.396000 | 0.000000 | 0.000000 | X:-0.1278,XD:-0.0012,TH:0.396,THD:0.000,W:0.000,U:0.000
0.037089 | BEAM_LOAD | 1 | 0 | STOPPED | 0.000000 | 0.000000 | -0.127800 | -0.001200 | 0.396000 | 0.000000 | 0.000000 | X:-0.1278,XD:-0.0012,TH:0.396,THD:0.000,W:0.000,U:0.000
0.046641 | BEAM_LOAD | 1 | 0 | STOPPED | 0.000000 | 0.000000 | -0.127800 | -0.001200 | 0.396000 | 0.000000 | 0.000000 | X:-0.1278,XD:-0.0012,TH:0.396,THD:0.000,W:0.000,U:0.000
0.056583 | BEAM_LOAD | 1 | 0 | STOPPED | 0.000000 | 0.000000 | -0.127800 | -0.001200 | 0.396000 | 0.000000 | 0.000000 | X:-0.1278,XD:-0.0012,TH:0.396,THD:0.000,W:0.000,U:0.000
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

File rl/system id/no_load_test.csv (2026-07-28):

t_s | test_name | test_run_id | test_active | phase_label | u_target | u_sent | x | xdot | th_deg | thdot_deg_s | w_deg_s | raw
0.005042 | NO_LOAD | 0 | 0 | STOPPED | 0.000000 | 0.000000 | -0.127800 | -0.000300 | -0.220000 | 0.000000 | 0.000000 | X:-0.1278,XD:-0.0003,TH:-0.220,THD:0.000,W:0.000,U:0.000
0.015122 | NO_LOAD | 0 | 0 | STOPPED | 0.000000 | 0.000000 | -0.127800 | -0.000300 | -0.220000 | 0.000000 | 0.000000 | X:-0.1278,XD:-0.0003,TH:-0.220,THD:0.000,W:0.000,U:0.000
0.025035 | NO_LOAD | 0 | 0 | STOPPED | 0.000000 | 0.000000 | -0.127800 | -0.000300 | -0.220000 | 0.000000 | 0.000000 | X:-0.1278,XD:-0.0003,TH:-0.220,THD:0.000,W:0.000,U:0.000
0.035041 | NO_LOAD | 0 | 0 | STOPPED | 0.000000 | 0.000000 | -0.127800 | -0.000300 | -0.220000 | 0.000000 | 0.000000 | X:-0.1278,XD:-0.0003,TH:-0.220,THD:0.000,W:0.000,U:0.000
0.045279 | NO_LOAD | 0 | 0 | STOPPED | 0.000000 | 0.000000 | -0.127800 | -0.000300 | -0.220000 | 0.000000 | 0.000000 | X:-0.1278,XD:-0.0003,TH:-0.220,THD:0.000,W:0.000,U:0.000
0.055122 | NO_LOAD | 0 | 0 | STOPPED | 0.000000 | 0.000000 | -0.127800 | -0.000300 | -0.220000 | 0.000000 | 0.000000 | X:-0.1278,XD:-0.0003,TH:-0.220,THD:0.000,W:0.000,U:0.000
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

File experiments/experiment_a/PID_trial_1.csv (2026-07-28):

time | time_rel | dt | x | xdot | theta | theta_deg | thdot | error | error_sq | d_raw | a_raw | w_raw
# Run: trial_1
# Controller: PID
# Start time: 2026-02-20 13:51:00
# Distance scale: 0.15 m per unit
1771570260.336608 | 0.023593 | 0.010000 | -0.011250 | 0.000000 | -0.005061 | -0.2900 | -0.000000 | 0.011250 | 0.00012656 | -0.075000 | -0.2900 | -0.000000
1771570260.345842 | 0.032827 | 0.009234 | -0.011400 | -0.016244 | -0.005061 | -0.2900 | -0.000000 | 0.011400 | 0.00012996 | -0.076000 | -0.2900 | -0.000000
1771570260.375576 | 0.062561 | 0.029733 | -0.011400 | 0.000000 | -0.005061 | -0.2900 | -0.000000 | 0.011400 | 0.00012996 | -0.076000 | -0.2900 | -0.000000
1771570260.385256 | 0.072241 | 0.009681 | -0.011400 | 0.000000 | -0.005061 | -0.2900 | -0.000000 | 0.011400 | 0.00012996 | -0.076000 | -0.2900 | -0.000000
1771570260.416837 | 0.103822 | 0.031580 | -0.011400 | 0.000000 | -0.005061 | -0.2900 | -0.000000 | 0.011400 | 0.00012996 | -0.076000 | -0.2900 | -0.000000
1771570260.425611 | 0.112596 | 0.008775 | -0.011400 | 0.000000 | -0.005061 | -0.2900 | -0.000000 | 0.011400 | 0.00012996 | -0.076000 | -0.2900 | -0.000000
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

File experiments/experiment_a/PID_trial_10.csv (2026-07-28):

time | time_rel | dt | x | xdot | theta | theta_deg | thdot | error | error_sq | d_raw | a_raw | w_raw
# Run: trial_10
# Controller: PID
# Start time: 2026-02-20 14:00:19
# Distance scale: 0.15 m per unit
1771570819.098296 | 0.015693 | 0.010000 | -0.017100 | 0.000000 | 0.005411 | 0.3100 | -0.000000 | 0.017100 | 0.00029241 | -0.114000 | 0.3100 | -0.000000
1771570819.106088 | 0.023485 | 0.007791 | -0.017250 | -0.019252 | 0.005411 | 0.3100 | -0.000000 | 0.017250 | 0.00029756 | -0.115000 | 0.3100 | -0.000000
1771570819.137794 | 0.055191 | 0.031706 | -0.017100 | 0.004731 | 0.005411 | 0.3100 | -0.000000 | 0.017100 | 0.00029241 | -0.114000 | 0.3100 | -0.000000
1771570819.146993 | 0.064390 | 0.009199 | -0.017250 | -0.016306 | 0.005411 | 0.3100 | -0.000000 | 0.017250 | 0.00029756 | -0.115000 | 0.3100 | -0.000000
1771570819.176589 | 0.093986 | 0.029597 | -0.017250 | 0.000000 | 0.005411 | 0.3100 | -0.000000 | 0.017250 | 0.00029756 | -0.115000 | 0.3100 | -0.000000
1771570819.186273 | 0.103670 | 0.009684 | -0.017250 | 0.000000 | 0.005411 | 0.3100 | -0.000000 | 0.017250 | 0.00029756 | -0.115000 | 0.3100 | -0.000000
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

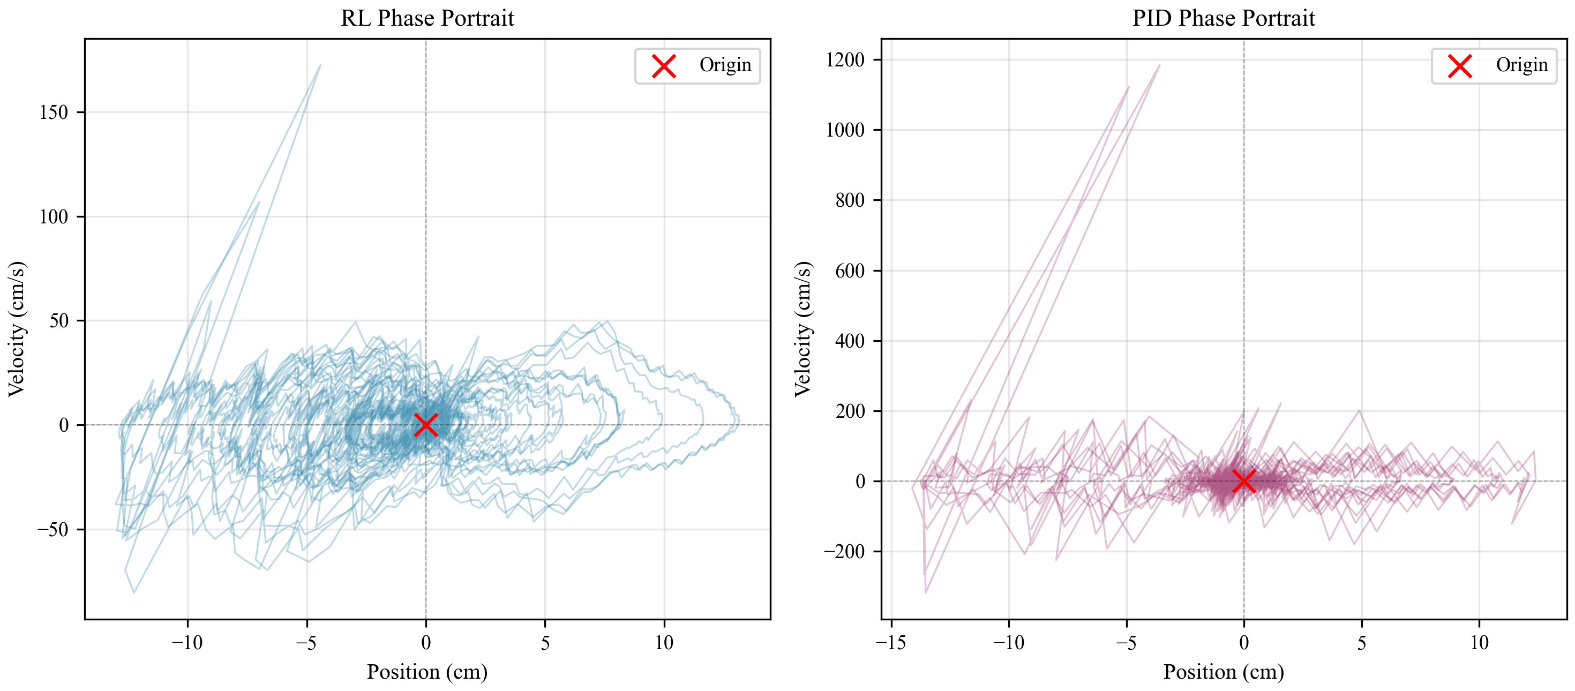
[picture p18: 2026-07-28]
experiments/results_experiment_c/fig5_phase_portrait.png

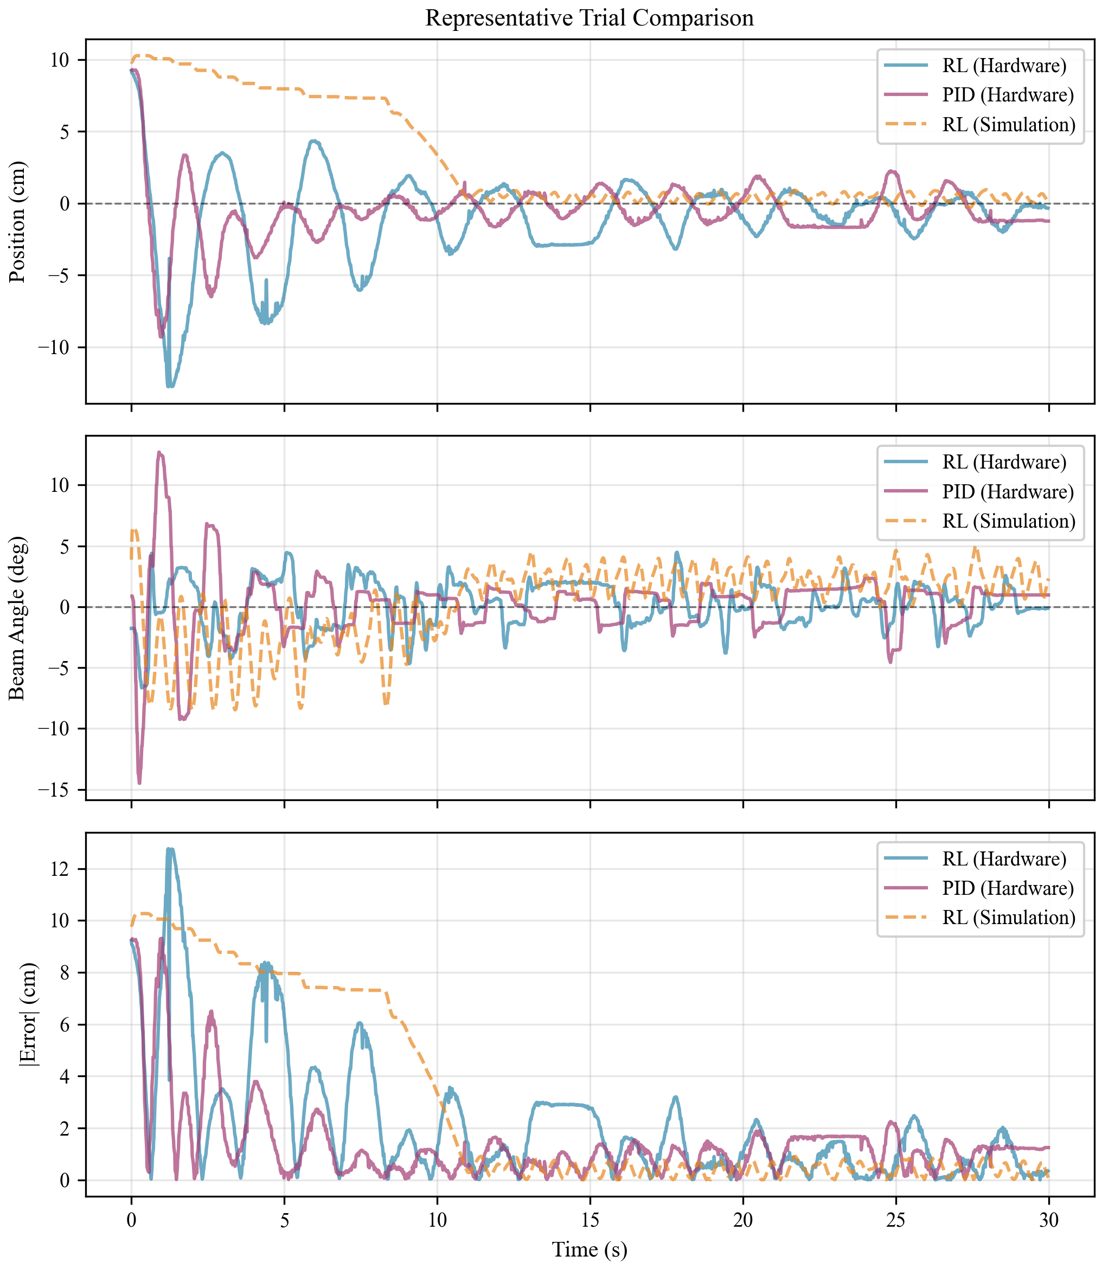
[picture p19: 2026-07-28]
experiments/results_experiment_b/fig1_trial_comparison.png

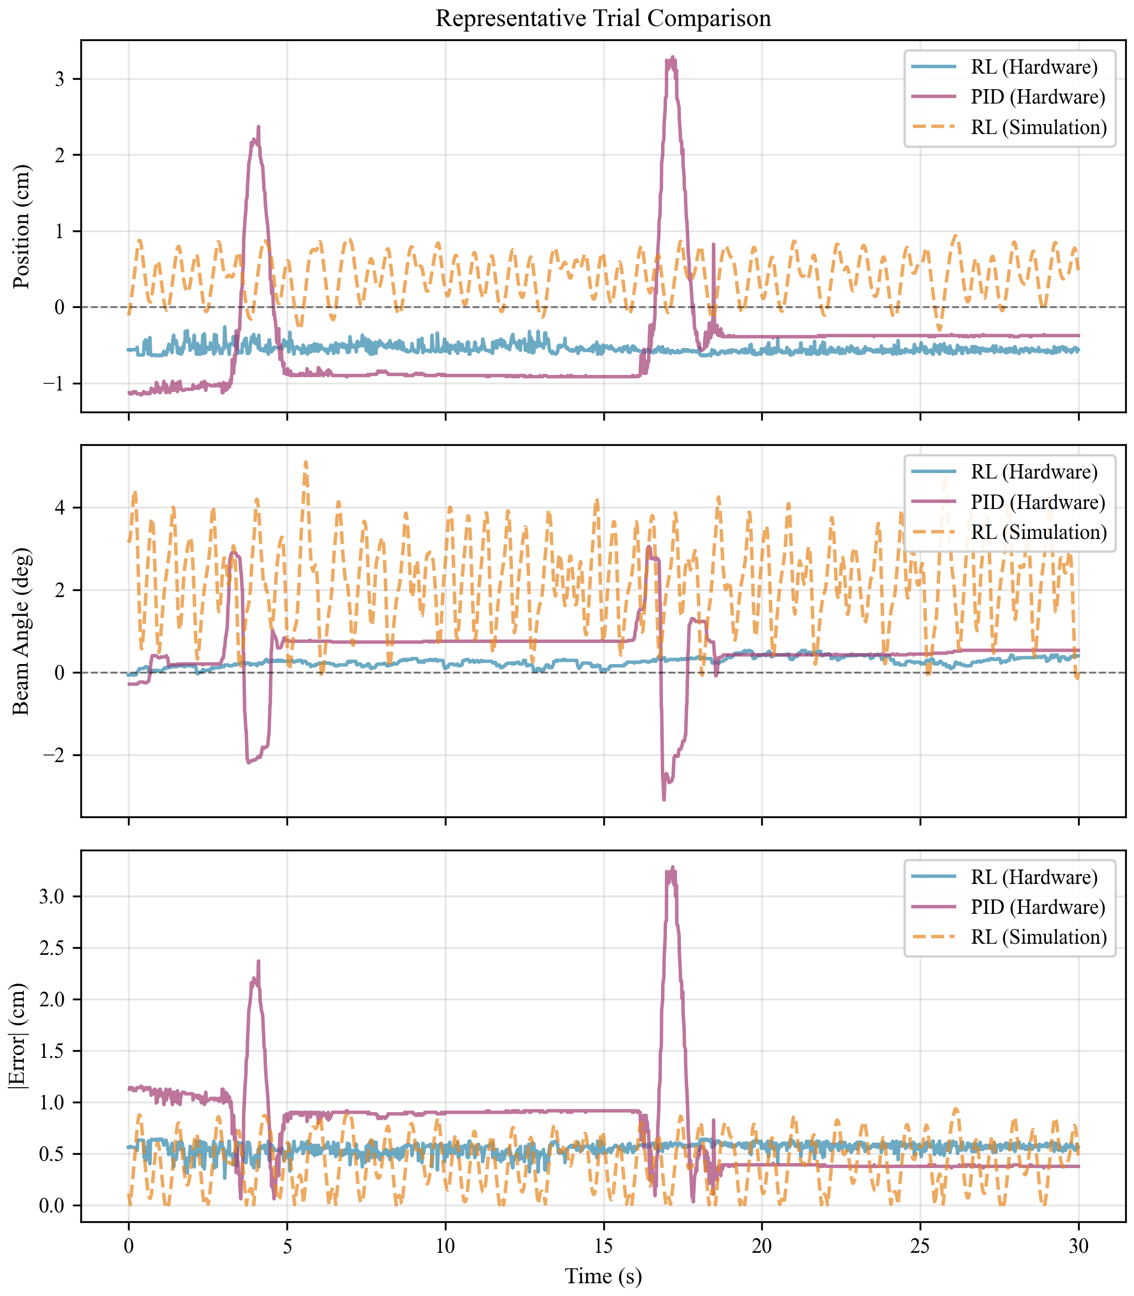
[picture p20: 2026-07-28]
experiments/results_experiment_a/fig1_trial_comparison.png

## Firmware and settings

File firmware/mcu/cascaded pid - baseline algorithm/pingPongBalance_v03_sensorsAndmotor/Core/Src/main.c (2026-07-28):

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
/* Includes ------------------------------------------------------------------*/
#include "main.h"
#include "usb_device.h"

/* USER CODE BEGIN Includes */
#include "dist_adc.h"
#include "ssd1306.h"
#include "fonts.h"
#include "mt6816.h"
#include "encoder_speed.h"
#include "motor_driver.h"
#include "virtual_wall.h"
#include <math.h>
#include "pid.h"
#include "usb_telemetry.h"
#include <string.h>
#include <stdio.h>
#include "stm32f4xx_hal.h"   // or your MCU family header
#include "usbd_cdc_if.h"

/* USER CODE END Includes */

/* USER CODE BEGIN PD */
extern uint8_t CDC_Transmit(const void* Buf, uint32_t Len);
/* USER CODE END PD */

ADC_HandleTypeDef hadc1;
DMA_HandleTypeDef hdma_adc1;

CRC_HandleTypeDef hcrc;

I2C_HandleTypeDef hi2c1;
DMA_HandleTypeDef hdma_i2c1_tx;

SPI_HandleTypeDef hspi1;
DMA_HandleTypeDef hdma_spi1_rx;
DMA_HandleTypeDef hdma_spi1_tx;

TIM_HandleTypeDef htim2;
TIM_HandleTypeDef htim3;
TIM_HandleTypeDef htim10;

void SystemClock_Config(void);
static void MX_GPIO_Init(void);
static void MX_DMA_Init(void);
static void MX_CRC_Init(void);
static void MX_I2C1_Init(void);
static void MX_SPI1_Init(void);
static void MX_TIM2_Init(void);
static void MX_TIM3_Init(void);
static void MX_ADC1_Init(void);
static void MX_TIM10_Init(void);
/* USER CODE BEGIN 0 */
#define ANGLE_MIN_DEG   -25.0f
#define ANGLE_MAX_DEG    25.0f
#define MOTOR_TO_ANGLE_SIGN   (+1)
MotorDriver_HandleTypeDef motor;

EncoderSpeed_Handle_t enc;
uint16_t mt6816_zero = 8344 & 0x3FFF; //Set Zero position here
MT6816_Handle_t mt6816;

#define ADC_DMA_LEN  64
static uint16_t adc_dma_buf[ADC_DMA_LEN];
static AdcDistance_t adcDist;

// -------- Cascaded PID --------
PID_TypeDef pidPos;   // outer: ball position -> angle setpoint
PID_TypeDef pidAng;   // inner: angle -> motor command

// Hardcoded defaults (edit these)
static const float DEFAULT_POS_KP = 22.302f;
static const float DEFAULT_POS_KI = 0.0f;
static const float DEFAULT_POS_KD = 4.587f;

static const float DEFAULT_ANG_KP = 0.02115f;
static const float DEFAULT_ANG_KI = 0.02104f;
static const float DEFAULT_ANG_KD = 0.0001710f;


// Outer PID (position)
double pos_in = 0.0, pos_out = 0.0, pos_sp = 0.0;  // pos_out = ang_sp (deg)

// Inner PID (angle)
double ang_in = 0.0, ang_out = 0.0, ang_sp = 0.0;  // ang_out = motor cmd [-1..+1]

// Start gains (tune later)
static double Kp_pos = DEFAULT_POS_KP, Ki_pos = DEFAULT_POS_KI, Kd_pos = DEFAULT_POS_KD;   // d -> degrees
static double Kp_ang = DEFAULT_ANG_KP, Ki_ang = DEFAULT_ANG_KI, Kd_ang = DEFAULT_ANG_KD;   // degrees -> cmd

// Optional: outer deadband to reduce jitter near center
static const float POS_DEADBAND = 0.01f; // normalized d


int findCharPosition(const char *buffer, size_t size, char character) {
    for (size_t i = 0; i < size; ++i) {
        if (buffer[i] == character) {
            return (int)i;
        }
    }
    return -1; // '\r' not found
}

void USB_CDC_RxHandler(uint8_t *buf, uint32_t len)
{
	USB_Command_Process(buf, len);
}

void HAL_I2C_MemTxCpltCallback(I2C_HandleTypeDef *hi2c) {
    ssd1306_I2C_TxCpltCallback(hi2c);
}

static void OLED_Render(float V, float P, float A, float R)
{
    char buf[32];

    ssd1306_Fill(Black);

    // Title
    ssd1306_SetCursor(0, 0);
    ssd1306_WriteString("Ball Beam", Font_11x18, White);

    // Second line: V
    ssd1306_SetCursor(0, 16);
    snprintf(buf, sizeof(buf), "V = %.3f V", V);
    ssd1306_WriteString(buf, Font_7x10, White);

    // Third line: P
    ssd1306_SetCursor(0, 28);
    snprintf(buf, sizeof(buf), "P = %.3f", P);
    ssd1306_WriteString(buf, Font_7x10, White);

    // Fourth line: A
    ssd1306_SetCursor(0, 40);
    snprintf(buf, sizeof(buf), "A = %.3f deg", A);
    ssd1306_WriteString(buf, Font_7x10, White);

    // Fifth line: R
    ssd1306_SetCursor(0, 52);
    snprintf(buf, sizeof(buf), "R = %.3f rad/s", R);
    ssd1306_WriteString(buf, Font_7x10, White);

    // Start non-blocking DMA flush (returns immediately)
    (void)ssd1306_UpdateScreen_DMA(&hi2c1);
}

void HAL_SPI_TxRxCpltCallback(SPI_HandleTypeDef * hspi)
{
//		absEnc_spiDone = 1;// TX-RX Done
		MT6816_SpiTxRxCpltCallback(&mt6816, hspi);
}

int32_t MT6816_GetZeroed_Int32(uint16_t raw14)
{
    // 1) Force to 14-bit
    uint16_t raw = raw14 & 0x3FFF;

    // 2) Zero with wrap in 14 bits
    uint16_t z = (raw - mt6816_zero) & 0x3FFF;   // 0..16383

    // 3) Convert to signed around 0
    //    0..8191  ->  0..8191
    //    8192..16383 -> -8192..-1
    if (z >= 8192U)
        return (int32_t)z - 16384;   // 16384 = 1 << 14
    else
        return (int32_t)z;
}
/* USER CODE END 0 */

/**
  * @brief  The application entry point.
  * @retval int
  */
int main(void)
{

  /* MCU Configuration--------------------------------------------------------*/

  /* Reset of all peripherals, Initializes the Flash interface and the Systick. */
  HAL_Init();

  /* Configure the system clock */
  SystemClock_Config();

  /* Initialize all configured peripherals */
  MX_GPIO_Init();
  MX_DMA_Init();
  MX_CRC_Init();
  MX_USB_DEVICE_Init();
  MX_I2C1_Init();
  MX_SPI1_Init();
  MX_TIM2_Init();
  MX_TIM3_Init();
  MX_ADC1_Init();
  MX_TIM10_Init();
  /* USER CODE BEGIN 2 */
  //Motor driver init
  uint32_t period = __HAL_TIM_GET_AUTORELOAD(&htim3);
  MotorDriver_Init(&motor,
                   &htim3,
                   TIM_CHANNEL_1,
                   GPIOB,
                   GPIO_PIN_3,
                   period,
                   GPIO_PIN_RESET);   // "forward" = pin low
  MotorDriver_Start(&motor);

  //Timer encoder counter init
  HAL_TIM_Encoder_Start(&htim2, TIM_CHANNEL_ALL);
  EncoderSpeed_Init(&enc, &htim2,
                        98u,      // counts_per_rev
                        14.0f,      // gear_ratio
                        0.001f);    // dt_s (TIM10 period)
  EncoderSpeed_SetLowPass(&enc, 2.0f);     // Hz cutoff
  HAL_TIM_Base_Start_IT(&htim10);

  //Abs enc command building
  MT6816_Init(&mt6816, &hspi1, 3);

  // Init lcd using one of the stm32HAL i2c typedefs
  if (ssd1306_Init(&hi2c1) != 0) {
//    ; //comment error handler if you plug out the board
	Error_Handler();
  }
  HAL_Delay(1000);

  ssd1306_Fill(Black);
  if (!ssd1306_IsBusy()) {
      // draw text into SSD1306_Buffer...
      ssd1306_UpdateScreen_DMA(&hi2c1);
  }

  HAL_Delay(1000);

  // Preset scaling:
  // we want distance = 0..1 over that window, inverted (near=1, far=0), with mild nonlinearity.

  AdcDist_Init(&adcDist, &hadc1,
               adc_dma_buf, ADC_DMA_LEN,
			   /* v_ref */ 3.3f,
			   /* adc_bits */ 12,
               /* v_low */ 0.44f,
               /* v_mid */ 1.73f,   // if not between low & high, it will auto-set to midpoint
               /* v_high*/ 3.0f,
               /* invert */ 0,
               /* gamma  */ 1.0f,
               /* compute_period_ms (unused) */ 0);
  AdcDist_SetFilterAlpha(&adcDist, 0.05);
//  AdcDist_SetMedianWindow(&adcDist, 5);
  AdcDist_Start(&adcDist);

  // ============ Cascaded PID ============

  g_ang_kp = DEFAULT_ANG_KP;
  g_ang_ki = DEFAULT_ANG_KI;
  g_ang_kd = DEFAULT_ANG_KD;

  g_pos_kp = DEFAULT_POS_KP;
  g_pos_ki = DEFAULT_POS_KI;
  g_pos_kd = DEFAULT_POS_KD;

  // Outer: ball position -> desired angle (deg)
  PID2(&pidPos,
       &pos_in,
       &pos_out,
       &pos_sp,
       Kp_pos, Ki_pos, Kd_pos,
       _PID_CD_REVERSE);   // REVERSE matches what you observed for ball centering

  PID_SetOutputLimits(&pidPos, ANGLE_MIN_DEG, ANGLE_MAX_DEG);
  pidPos.SampleTime = 10;                 // outer slower (50 Hz is plenty)
  PID_SetMode(&pidPos, _PID_MODE_AUTOMATIC);

  // Inner: angle -> motor command [-1..+1]
  PID2(&pidAng,
       &ang_in,
       &ang_out,
       &ang_sp,
       Kp_ang, Ki_ang, Kd_ang,
       _PID_CD_DIRECT);

  PID_SetOutputLimits(&pidAng, -1.0, 1.0);  // start limited while tuning
  pidAng.SampleTime = 3;                     // inner faster (100 Hz)
  PID_SetMode(&pidAng, _PID_MODE_AUTOMATIC);

  // Targets
  pos_sp = 0.0;
  ang_sp = 0.0;

  uint32_t last_print = HAL_GetTick();
  uint32_t last_motorStep = HAL_GetTick();

  /* USER CODE END 2 */

  /* Infinite loop */
  /* USER CODE BEGIN WHILE */
  while (1)
  {
    /* USER CODE END WHILE */

    /* USER CODE BEGIN 3 */
    uint32_t now = HAL_GetTick();
    AdcDist_Update(&adcDist);
    MT6816_Update(&mt6816, now);

    /////////////////////////////

    if (now - last_print >= 20)
    {
      uint8_t buf[64];
	  last_print = now;
	  float v = AdcDist_GetVoltage(&adcDist);
	  float d = -(2*AdcDist_GetDistance(&adcDist)-1); //0-1, scaled to -1 to 1;

	  uint16_t A_raw;
	  MT6816_GetRaw(&mt6816, &A_raw);
	  float A = MT6816_GetZeroed_Int32(A_raw)*(360.0/16384.0);

	  float r = EncoderSpeed_GetOutputRadPerSecFilt(&enc);

	  if (!ssd1306_IsBusy()) {
	      OLED_Render(v, d, A, r);
	  }

	  int len = snprintf((char*)buf, sizeof(buf),
	      "D:%.3f,A:%.2f,W:%.3f\n",
	      d, A, r);

	  CDC_Transmit_FS(buf, (uint16_t)len);

    }
    if ((now - last_motorStep) >= 10)
    {
        last_motorStep = now;

        // ---- 1) Update ball position ----
        AdcDist_Update(&adcDist);
        float d = 2.0f * AdcDist_GetDistance(&adcDist) - 1.0f;

        // ---- 2) Read beam angle ----
        uint16_t A_raw;
        MT6816_GetRaw(&mt6816, &A_raw);
        float A = MT6816_GetZeroed_Int32(A_raw) * (360.0f / 16384.0f);

        // ---- 3) OUTER loop inputs ----
        float d_for_pid = d;
        if (fabsf(d_for_pid) < POS_DEADBAND) d_for_pid = 0.0f;

        float r = EncoderSpeed_GetOutputRadPerSecFilt(&enc);

        pos_in = (double)d_for_pid;
        pos_sp = (double)g_pos_sp;


		PID_SetTunings(&pidPos, g_pos_kp, g_pos_ki, g_pos_kd);

		// If outer gains all zero, clear memory
		if (fabsf(g_pos_kp) < 1e-6f && fabsf(g_pos_ki) < 1e-6f && fabsf(g_pos_kd) < 1e-6f)
		{
			pidPos.OutputSum = 0.0;
			pidPos.LastInput = pos_in;
			pos_out = 0.0;
		}

        PID_Compute(&pidPos);
        ang_sp = pos_out;

        if (!g_outer_loop_armed)
        {
            ang_sp = 0.0;
            // Clear outer loop integrator to prevent windup
            pidPos.OutputSum = 0.0;
            pidPos.LastInput = pos_in;
        }


        // Slew-rate limit on ang_sp (deg per 10ms tick)
        static float ang_sp_f = 0.0f;
        const float MAX_STEP_DEG = 1.0f; // try 0.5..2.0

        float target = (float)ang_sp;
        float delta  = target - ang_sp_f;

        if (delta >  MAX_STEP_DEG) delta =  MAX_STEP_DEG;
        if (delta < -MAX_STEP_DEG) delta = -MAX_STEP_DEG;

        ang_sp_f += delta;
        ang_sp = (double)ang_sp_f;


        // Safety clamp
        if (ang_sp > ANGLE_MAX_DEG) ang_sp = ANGLE_MAX_DEG;
        if (ang_sp < ANGLE_MIN_DEG) ang_sp = ANGLE_MIN_DEG;

        // ---- 6) INNER loop input ----
        ang_in = (double)A;

        // ---- 7) Update INNER tunings if changed ----
        static float last_ang_kp = -1.0f, last_ang_ki = -1.0f, last_ang_kd = -1.0f;
        if (g_ang_kp != last_ang_kp || g_ang_ki != last_ang_ki || g_ang_kd != last_ang_kd)
        {
            last_ang_kp = g_ang_kp;
            last_ang_ki = g_ang_ki;
            last_ang_kd = g_ang_kd;

            PID_SetTunings(&pidAng, g_ang_kp, g_ang_ki, g_ang_kd);

            // If inner gains all zero, clear memory + force output 0
            if (fabsf(g_ang_kp) < 1e-6f && fabsf(g_ang_ki) < 1e-6f && fabsf(g_ang_kd) < 1e-6f)
            {
                pidAng.OutputSum = 0.0;
                pidAng.LastInput = ang_in;
                ang_out = 0.0;
            }
        }

        // ---- 8) Compute INNER and drive motor ----
        if (PID_Compute(&pidAng))
        {
            float cmd = (float)ang_out;   // expected in [-1..+1] if pidAng limits are set that way

            float safe_cmd = VirtualWall_Apply(cmd,
                                               A,
                                               ANGLE_MIN_DEG,
                                               ANGLE_MAX_DEG,
                                               MOTOR_TO_ANGLE_SIGN);

            // If wall clamps to zero while we are trying to push, kill integrators & brake
            if (safe_cmd == 0.0f && cmd != 0.0f)
            {
                pidAng.OutputSum = 0.0;
                pidAng.LastInput = ang_in;

                pidPos.OutputSum = 0.0;
                pidPos.LastInput = pos_in;

                float w = EncoderSpeed_GetOutputRadPerSecFilt(&enc);
                float brake = -0.2f * w;
                if (brake >  1.0f) brake =  1.0f;
                if (brake < -1.0f) brake = -1.0f;
                MotorDriver_SetSpeed(&motor, brake);
            }
            else
            {
                MotorDriver_SetSpeed(&motor, safe_cmd);
            }
        }
        else
        {
            // Optional: if PID didn't compute this tick, keep applying last command or do nothing
            // MotorDriver_SetSpeed(&motor, last_cmd);
        }
    }


  }

  /* USER CODE END 3 */
}

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
/**
  * @brief  Period elapsed callback in non blocking mode
  * @note   This function is called  when TIM11 interrupt took place, inside
  * HAL_TIM_IRQHandler(). It makes a direct call to HAL_IncTick() to increment
  * a global variable "uwTick" used as application time base.
  * @param  htim : TIM handle
  * @retval None
  */
void HAL_TIM_PeriodElapsedCallback(TIM_HandleTypeDef *htim)
{
  /* USER CODE BEGIN Callback 0 */
  if (htim->Instance == TIM10)   // TIM10 update event
  {
      EncoderSpeed_Update(&enc);
      AdcDist_Update(&adcDist);
  }
  /* USER CODE END Callback 0 */
  if (htim->Instance == TIM11)
  {
    HAL_IncTick();
  }
}

/**
  * @brief  This function is executed in case of error occurrence.
  * @retval None
  */
void Error_Handler(void)
{
  /* USER CODE BEGIN Error_Handler_Debug */
  /* User can add his own implementation to report the HAL error return state */
  __disable_irq();
  while (1)
  {
  }
  /* USER CODE END Error_Handler_Debug */
}
#ifdef USE_FULL_ASSERT
/**
  * @brief  Reports the name of the source file and the source line number
  *         where the assert_param error has occurred.
  * @param  file: pointer to the source file name
  * @param  line: assert_param error line source number
  * @retval None
  */
void assert_failed(uint8_t *file, uint32_t line)
{
  /* USER CODE BEGIN 6 */
  /* User can add his own implementation to report the file name and line number,
     ex: printf("Wrong parameters value: file %s on line %d\r\n", file, line) */
  /* USER CODE END 6 */
}
#endif /* USE_FULL_ASSERT */

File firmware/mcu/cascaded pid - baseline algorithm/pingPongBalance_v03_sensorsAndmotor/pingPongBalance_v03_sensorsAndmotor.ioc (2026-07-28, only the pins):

Mcu.UserName=STM32F401CCUx
PA0-WKUP.Signal=S_TIM2_CH1_ETR
PA1.Signal=S_TIM2_CH2
PA11.Signal=USB_OTG_FS_DM
PA12.Signal=USB_OTG_FS_DP
PA2.Signal=SharedAnalog_PA2
PA4.Signal=SPI1_NSS
PA5.Signal=SPI1_SCK
PA6.Signal=SPI1_MISO
PA7.Signal=SPI1_MOSI
PA8.Signal=GPIO_Output
PB3.Signal=GPIO_Output
PB4.Signal=S_TIM3_CH1
PB6.Signal=I2C1_SCL
PB7.Signal=I2C1_SDA
PC14-OSC32_IN.Signal=RCC_OSC32_IN
PC15-OSC32_OUT.Signal=RCC_OSC32_OUT

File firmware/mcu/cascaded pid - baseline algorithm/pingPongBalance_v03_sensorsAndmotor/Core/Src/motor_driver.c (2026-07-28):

/*
 * motor_driver.c
 *
 *  Created on: Nov 16, 2025
 *      Author: USER-PC
 */


#include "motor_driver.h"
#include <math.h>

static uint32_t clamp_u32(uint32_t val, uint32_t min, uint32_t max)
{
    if (val < min) return min;
    if (val > max) return max;
    return val;
}

void MotorDriver_Init(MotorDriver_HandleTypeDef *hmotor,
                      TIM_HandleTypeDef *htim,
                      uint32_t channel,
                      GPIO_TypeDef *dir_port,
                      uint16_t dir_pin,
                      uint32_t pwm_period,
                      GPIO_PinState forwardLevel)
{
    hmotor->htim            = htim;
    hmotor->channel         = channel;
    hmotor->dir_port        = dir_port;
    hmotor->dir_pin         = dir_pin;
    hmotor->pwm_period      = pwm_period;
    hmotor->forwardDirLevel = forwardLevel;

    // Optional: default duty = 0
    __HAL_TIM_SET_COMPARE(hmotor->htim, hmotor->channel, 0U);
}

HAL_StatusTypeDef MotorDriver_Start(MotorDriver_HandleTypeDef *hmotor)
{
    return HAL_TIM_PWM_Start(hmotor->htim, hmotor->channel);
}

HAL_StatusTypeDef MotorDriver_Stop(MotorDriver_HandleTypeDef *hmotor)
{
    // Force duty to zero before stopping
    __HAL_TIM_SET_COMPARE(hmotor->htim, hmotor->channel, 0U);
    return HAL_TIM_PWM_Stop(hmotor->htim, hmotor->channel);
}

void MotorDriver_SetDuty(MotorDriver_HandleTypeDef *hmotor, float duty)
{
    if (duty < 0.0f) duty = 0.0f;
    if (duty > 1.0f) duty = 1.0f;

    float compare_f = duty * (float)hmotor->pwm_period;
    uint32_t compare = (uint32_t)(compare_f + 0.5f);

    compare = clamp_u32(compare, 0U, hmotor->pwm_period);
    __HAL_TIM_SET_COMPARE(hmotor->htim, hmotor->channel, compare);
}

void MotorDriver_SetSpeed(MotorDriver_HandleTypeDef *hmotor, float speed)
{
    // Clamp to [-1, 1]
    if (speed > 1.0f)  speed = 1.0f;
    if (speed < -1.0f) speed = -1.0f;

    // Set direction according to sign
    if (speed > 0.0f)
    {
        HAL_GPIO_WritePin(hmotor->dir_port, hmotor->dir_pin, hmotor->forwardDirLevel);
    }
    else if (speed < 0.0f)
    {
        HAL_GPIO_WritePin(hmotor->dir_port, hmotor->dir_pin,
                          (hmotor->forwardDirLevel == GPIO_PIN_SET) ? GPIO_PIN_RESET : GPIO_PIN_SET);
    }
    else
    {
        // speed == 0 -> duty 0. Direction pin left unchanged (you can change this if needed).
    }

    // Magnitude -> PWM duty
    float mag = fabsf(speed);
    MotorDriver_SetDuty(hmotor, mag);
}

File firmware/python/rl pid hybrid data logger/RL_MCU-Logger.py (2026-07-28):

"""
Hardware Inference for Ball-on-Beam Platform
CSV Logger for Paper Data Collection and PID Comparison
"""

import time
import math
import threading
import queue
import re
import csv
from dataclasses import dataclass
from typing import Optional, Dict, List, Tuple
from pathlib import Path
from collections import deque

import numpy as np
import serial
import serial.tools.list_ports
import tkinter as tk
from tkinter import ttk, messagebox, filedialog

from stable_baselines3 import SAC


# =============================================================================
# CONFIGURATION
# =============================================================================

class Config:
    """Centralized configuration for hardware control"""
    
    # Paths
    BASE_DIR = Path(__file__).resolve().parent
    MODEL_DIR = BASE_DIR / "models"
    MODEL_NAME = "sac_ballbeam_simple_32"
    DEFAULT_MODEL_PATH = MODEL_DIR / MODEL_NAME
    
    # Serial communication
    DEFAULT_BAUD = 115200
    DEFAULT_SEND_HZ = 100
    DEFAULT_TIMEOUT_S = 0.25
    
    # Telemetry units from MCU
    ANGLE_IS_DEG = True
    RATE_IS_DEG_PER_S = True
    
    # Command protocol
    TX_SETPOINT_CMD = "THSP"
    TX_STOP_CMD = "STOP"
    TX_RESET_CMD = "RST"
    
    # Action mapping
    DEFAULT_ANGLE_LIMIT_DEG = 25.0
    DEFAULT_A_DEADZONE = 0.0
    DEFAULT_A_CLAMP = 1.0
    DEFAULT_SP_RATE_LIMIT_DEGPS = 120.0
    DEFAULT_SP_NOISE_DEG = 0.0
    DEFAULT_FLIP_X = False
    
    # Observation bias (for centering)
    DEFAULT_X_BIAS = 0.0  # Set to -0.02 if ball settles at +2cm
    
    # CSV logging
    DEFAULT_CSV_BUFFER_SIZE = 100  # Write every N samples
    
    # Trial timing
    TRIAL_DURATION_S = 30.0  # Auto-stop after this duration
    
    # Observation space (6D: x, xdot, theta, thdot, theta_cmd, theta_cmd_dot)
    OBS_DIM = 6
    
    # State limits (for reference, not normalization)
    X_MAX = 0.15  # meters
    XD_MAX = 0.6  # m/s
    TH_MAX = math.radians(25.0)  # rad
    THD_MAX = math.radians(300.0)  # rad/s
    THCMD_MAX = TH_MAX
    
    # Actuator model (must match training)
    DEFAULT_SERVO_DELAY_STEPS = 2
    DEFAULT_SERVO_TAU_S = 0.04


# =============================================================================
# DATA STRUCTURES
# =============================================================================

@dataclass
class Telemetry:
    """Telemetry data from MCU"""
    t_wall: float
    x: Optional[float] = None  # meters
    xdot: Optional[float] = None  # m/s
    theta: Optional[float] = None  # rad
    thdot: Optional[float] = None  # rad/s
    theta_cmd: Optional[float] = None  # rad (MCU's actual command)
    motor_speed: Optional[float] = None  # rad/s
    raw: str = ""
    
    def is_valid(self) -> bool:
        """Check if all required fields are present"""
        return all([
            self.x is not None,
            self.xdot is not None,
            self.theta is not None,
            self.thdot is not None
        ])


@dataclass
class ObservationState:
    """Full 6D observation state"""
    x: float
    xdot: float
    theta: float
    thdot: float
    theta_cmd: float
    theta_cmd_dot: float
    
    def to_array(self) -> np.ndarray:
        """Convert to numpy array for policy input"""
        return np.array([
            self.x,
            self.xdot,
            self.theta,
            self.thdot,
            self.theta_cmd,
            self.theta_cmd_dot
        ], dtype=np.float32)


# =============================================================================
# TELEMETRY PARSING
# =============================================================================

def parse_kv_telemetry(line: str) -> Dict[str, float]:
    """
    Parse key-value telemetry lines.
    Example: "X:0.0123,XD:-0.01,TH:2.50,THD:-12.0,W:123.4"
    Returns dict of {key: float}.
    """
    out: Dict[str, float] = {}
    parts = re.split(r"[,\s]+", line.strip())
    for p in parts:
        if ":" in p:
            k, v = p.split(":", 1)
            k = k.strip().upper()
            v = v.strip()
            try:
                out[k] = float(v)
            except ValueError:
                pass
    return out


def build_telemetry_from_dict(kv: Dict[str, float], t_wall: float, raw: str) -> Telemetry:
    """
    Build Telemetry object from parsed key-value dict.
    Handles unit conversions from MCU to SI units.
    """
    tel = Telemetry(t_wall=t_wall, raw=raw)
    
    # Position and velocity (assume meters)
    tel.x = kv.get("X")
    tel.xdot = kv.get("XD")
    
    # Angle measurements
    if "TH" in kv:
        th_val = kv["TH"]
        tel.theta = math.radians(th_val) if Config.ANGLE_IS_DEG else th_val
    
    if "THD" in kv:
        thd_val = kv["THD"]
        tel.thdot = math.radians(thd_val) if Config.RATE_IS_DEG_PER_S else thd_val
    
    # Command angle (from MCU)
    if "THCMD" in kv:
        thcmd_val = kv["THCMD"]
        tel.theta_cmd = math.radians(thcmd_val) if Config.ANGLE_IS_DEG else thcmd_val
    
    # Motor speed
    if "W" in kv:
        w_val = kv["W"]
        tel.motor_speed = math.radians(w_val) if Config.RATE_IS_DEG_PER_S else w_val
    
    return tel


# =============================================================================
# SERVO MODEL
# =============================================================================
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

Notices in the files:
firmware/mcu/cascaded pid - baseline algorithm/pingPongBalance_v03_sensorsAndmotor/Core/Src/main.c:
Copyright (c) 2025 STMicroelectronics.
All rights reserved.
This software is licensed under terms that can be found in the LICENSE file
